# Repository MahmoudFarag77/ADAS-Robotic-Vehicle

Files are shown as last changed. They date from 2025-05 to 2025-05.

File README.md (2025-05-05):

# 🚗 ADAS Robotic Vehicle Prototype – Embedded, Vision, and Control Systems

This project is a fully integrated **Advanced Driver Assistance System (ADAS)** prototype with mechanical steering, embedded control, and computer vision. It simulates real-world ADAS features using a combination of **ESP32**, **Raspberry Pi 4**, **FreeRTOS**, and **YOLOv8**, with an integrated SolidWorks mechanical design.

---

## 🧠 Key ADAS Features

| Feature  | Description |
|---|---|
| **AEB**  | Autonomous Emergency Braking using front ultrasonic sensor |
| **ACC**  | Adaptive Cruise Control with automatic speed regulation |
| **LKA**  | Lane Keeping Assist with dual IR sensors and servo steering |
| **TSDR** | Traffic Sign Detection & Recognition via Raspberry Pi + OpenCV + YOLO |
| **BSW**  | Blind Spot Warning using side-mounted ultrasonic sensors |
| **ALS**  | Adaptive Light System with ambient light sensing and LED control |

---

## ⚙️ System Overview

- **Main Controller:** ESP32 (C++, Arduino IDE)
- **Vision Controller:** Raspberry Pi 4 (Python, OpenCV, YOLO)
- **Communication:** I2C (ESP32 ↔ RPi), UART (ESP32 ↔ Bluetooth)
- **Power:** 2x 18650 Li-ion batteries + 5V 3A RPi power bank

---

## 🛠 Technologies Used

- **Embedded:** ESP32, FreeRTOS
- **Computer Vision:** Raspberry Pi 4, OpenCV, YOLOv8
- **Communication:** I2C, UART (Bluetooth)
- **Mechanical CAD:** SolidWorks 2020
- **Simulation:** Manual testing + real-time behavior demos

---

## 🧰 Bill of Materials (BOM)

View full BOM [here](Docs/BOM.md) or summarized below:

- **Microcontrollers:** ESP32, Raspberry Pi 4
- **Actuators:** 2x DC TT motors, 1x SG90 servo
- **Sensors:** 3x Ultrasonic (HC-SR04), 2x IR, 1x LDR
- **Camera:** Raspberry Pi Camera V1.3
- **Power:** 2x 18650 Li-ion, 1x 5V 3A Power Bank
- **Indicators:** Red, Yellow, and White LEDs for brake, hazard, and headlights

---

## 🧑‍💻 Code Repositories

### 🟦 ESP32 – Embedded Control
📁 [`ESP32_Code/`](ESP32_Code/ESP32_Code.ino)

Implements:
- Manual control via Bluetooth
- AEB, ACC, LKA, BSW, ALS
- Real-time task scheduling with FreeRTOS

### 📚 ESP32 Firmware Dependencies

The following libraries are used in the ESP32 embedded firmware. Make sure they are installed in your Arduino IDE before uploading:

| Library | Use Case |
|---|---|
| `Arduino.h` | Core Arduino functions |
| `freertos/FreeRTOS.h`  | FreeRTOS base for real-time operations |
| `freertos/task.h` | Task creation and management in FreeRTOS |
| `BluetoothSerial.h` | Bluetooth communication with mobile app  |
| `ESP32Servo.h` | Servo control for front wheel steering |
| `Wire.h` | I2C communication with Raspberry Pi |

> 💡 Tip: Most libraries are preinstalled with ESP32 board support in Arduino. If not, install via **Library Manager** (Sketch → Include Library → Manage Libraries).

### 🟨 Raspberry Pi – Computer Vision
📁 [`RaspberryPi_Code/`](RaspberryPi_Code/TSDR.py)

Implements:
- YOLOv8-based TSDR (Traffic Sign Detection and Recognition)
- Python script
- I2C master communication to send detection data to ESP32

### 🧠 Raspberry Pi – TSDR Python Dependencies

The Traffic Sign Detection and Recognition (TSDR) module is written in Python and uses the following libraries:

| Library | Description |
|---|---|
| `cv2` (OpenCV) | Core library for image processing and visualization |
| `picamera2` | Captures real-time video from the Raspberry Pi Camera |
| `ultralytics` | Runs YOLOv8 model for real-time traffic sign detection and classification  |
| `cvzone` | Simplifies display of bounding boxes, FPS counter, etc. |
| `pandas` | (Optional) Used for handling datasets or logging predictions |
| `numpy` | Numerical operations and array handling for image data |
| `smbus2` | I2C communication between Raspberry Pi and ESP32 |
| `time` (built-in) | Delay functions, timeouts, and logging |

> 🛠️ To install manually:
> ```bash
> pip install opencv-python picamera2 ultralytics cvzone pandas numpy smbus2
> ```

---

## 🛠️ Mechanical Design

📁 [`SolidWorks_Model/`](SolidWorks_Model/)

- Full CAD of the 4-wheel chassis
- Steering and motor integration
- Rendered previews available in [`Media/`](Media/)

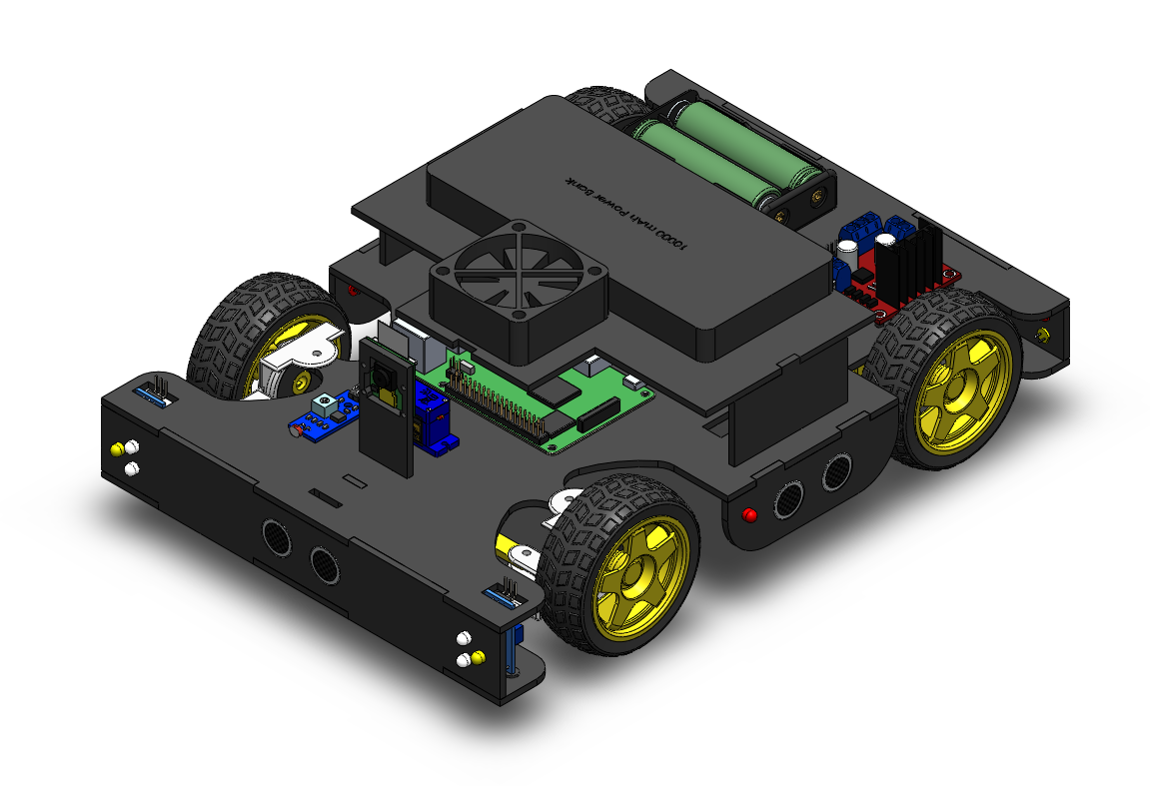
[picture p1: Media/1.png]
Chassis Render


---

## 🎥 Demo

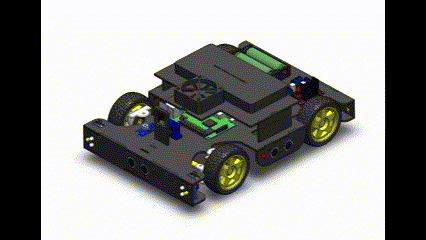
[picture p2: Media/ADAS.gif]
Demo


> 💡 Want to see specific features in action? [Add links to YouTube or external videos if needed]

---

## 🧭 System Architecture
- System Architectures are available in [`Docs/`](Docs/)

---

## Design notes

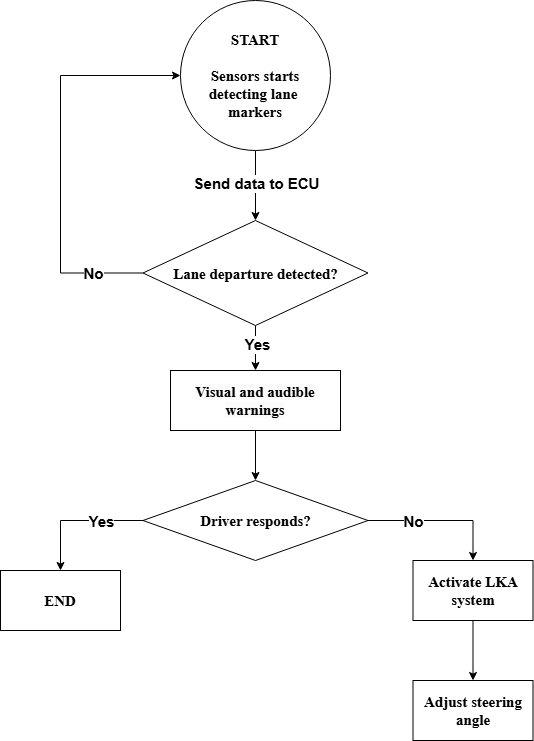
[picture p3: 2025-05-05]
Docs/LKA_FlowChart.png

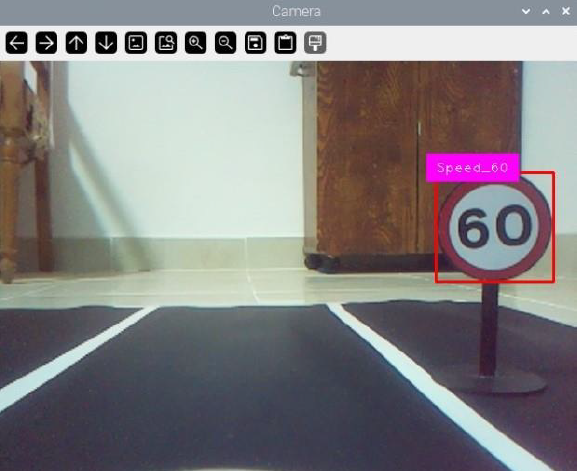
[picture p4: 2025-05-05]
Docs/TSDR_60.png

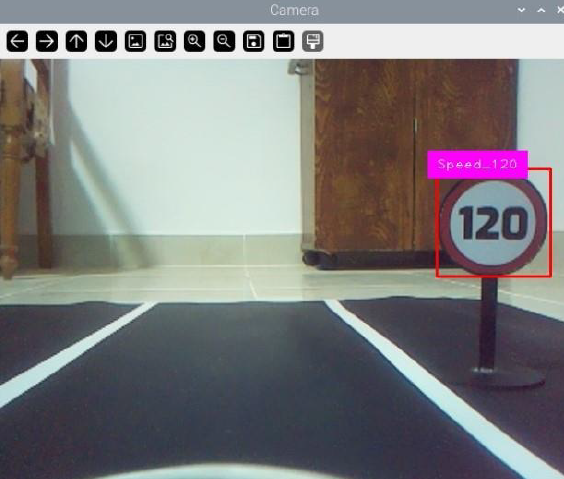
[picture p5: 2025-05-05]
Docs/TSDR_120.png

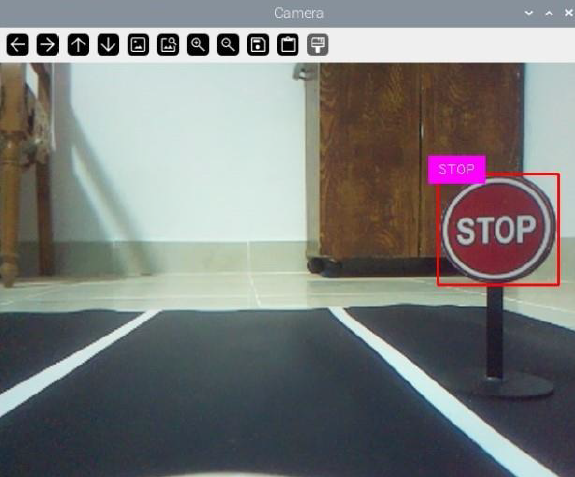
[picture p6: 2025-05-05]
Docs/TSDR_STOP.png

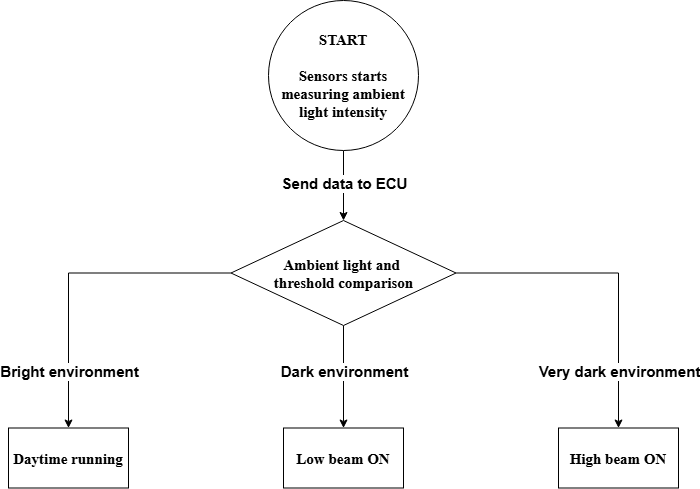
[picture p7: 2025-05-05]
Docs/ALS_FlowChart.png

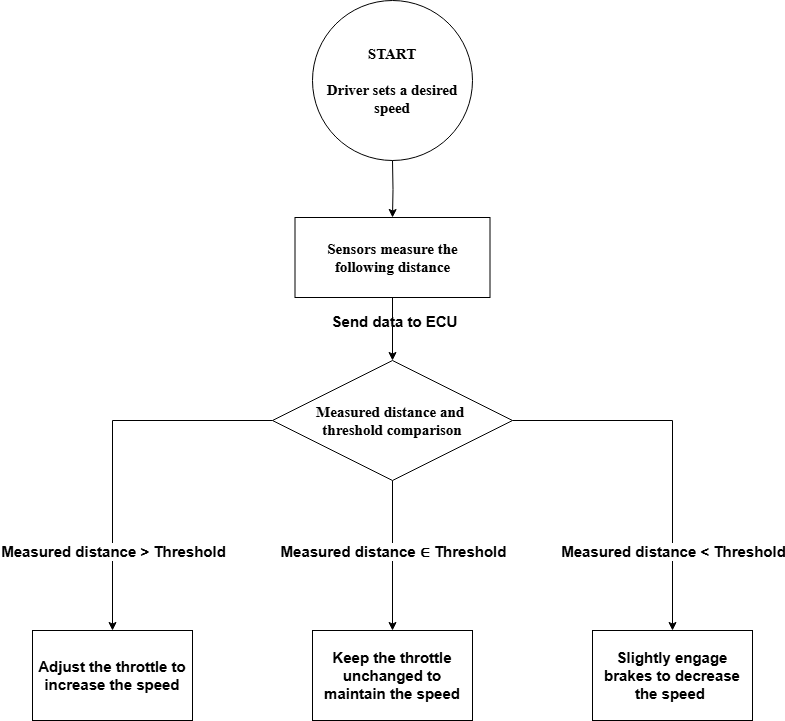
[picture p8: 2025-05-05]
Docs/ACC_FlowChart.png

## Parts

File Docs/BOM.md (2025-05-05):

# 📦 Bill of Materials (BOM) – ADAS Robotic Vehicle Prototype

This document outlines all the electronic components, sensors, actuators, and power elements used in the ADAS robotic vehicle prototype.

---

## 🧠 Microcontrollers & Processing Units

| Item | Quantity | Description |
|---|---|---|
| Raspberry Pi 4 | 1 | Main processor for computer vision (TSDR) |
| ESP32 DevKit | 1 | Main embedded controller for low-level functions |

---

## 🎯 Sensors

| Sensor/Module | Quantity | Functionality |
|---|---|---|
| HC-SR04 Ultrasonic Sensor| 3 | Distance sensing for AEB, ACC, and BSW |
| IR Sensor Module | 2 | Lane detection for LKA |
| LDR Photocell | 1 | Ambient light sensing for ALS |
| Raspberry Pi Camera V1.3 | 1 | Visual input for traffic sign detection (TSDR) |

---

## ⚙️ Actuators & Motors

| Item | Quantity | Description |
|---|---|---|
| DC TT Geared Motor | 2 | Rear wheel drive (left and right motors) |
| SG90 Servo Motor | 1 | Front wheel steering mechanism |
| 5V DC Cooling Fan  | 1 | Raspberry Pi heat management |

---

## 💡 Indicators (LEDs)

| LED Type | Quantity | Functionality |
|---|---|---|
| Red LED | 4 | Brake lights & Blind Spot Warning |
| Yellow LED | 4 | Hazard indicators |
| White LED | 4 | Adaptive headlights (ALS system) |

---

## 🔌 Power & Supply

| Component | Quantity | Description |
|---|---|---|
| 18650 3.7V Battery | 2 | Power supply for motors and ESP32 |
| 5V 3A Power Bank | 1 | Power supply for Raspberry Pi |

---

## 🔧 Electronic Modules

| Module | Quantity | Description |
|---|---|---|
| L298N Motor Driver | 1 | Controls DC motors (rear wheel drive)  |

---

## 🔗 Communication

| Interface | Use Case |
|---|---|
| I2C | Communication between ESP32 and RPi |
| UART (Bluetooth) | Manual control via mobile app |

---

## 🛠️ Software & Development Tools

| Tool/Library | Platform | Purpose |
|---|---|---|
| Arduino IDE | ESP32 | Programming & deployment |
| FreeRTOS | ESP32 | Real-time task scheduling |
| Python + OpenCV | Raspberry Pi  | Image processing (TSDR) |
| YOLOv8 | Raspberry Pi  | Traffic sign detection & recognition|

---

> 📝 *All items were selected based on low cost, availability, and ease of integration for prototyping purposes.*

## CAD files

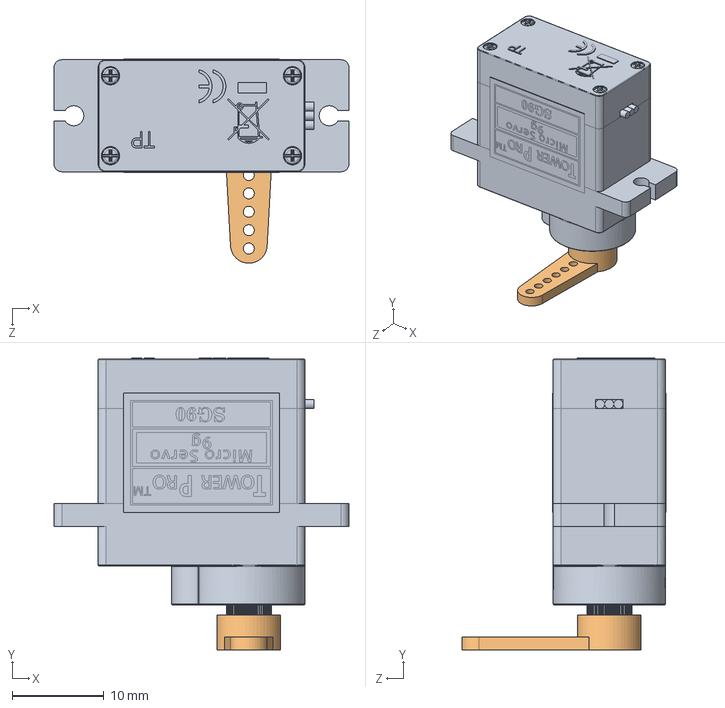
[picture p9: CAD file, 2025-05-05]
SolidWorks_Model/Servo Assembly.SLDASM
32.1 x 31.8 x 22.2 mm
SG90 Servo
SG90 Arm

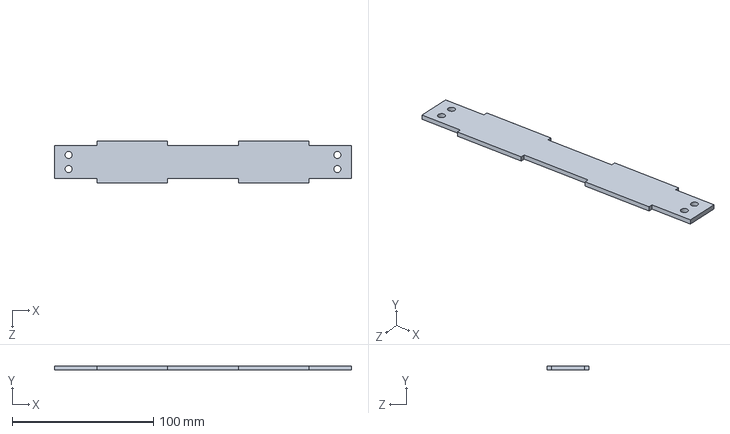
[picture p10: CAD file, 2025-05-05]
SolidWorks_Model/Back.SLDPRT
210.0 x 3.00 x 29.7 mm

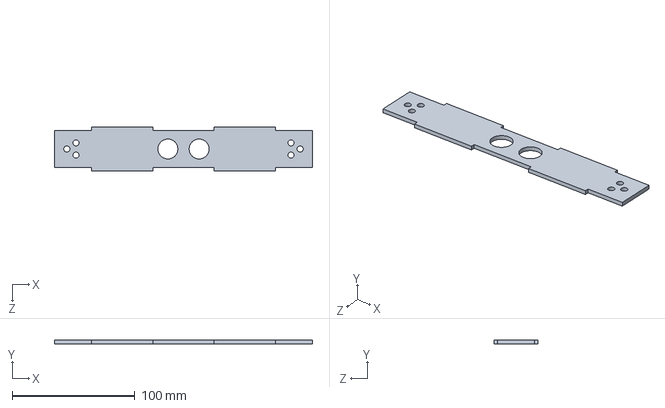
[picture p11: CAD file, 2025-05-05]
SolidWorks_Model/Front.SLDPRT
210.0 x 3.00 x 36.0 mm

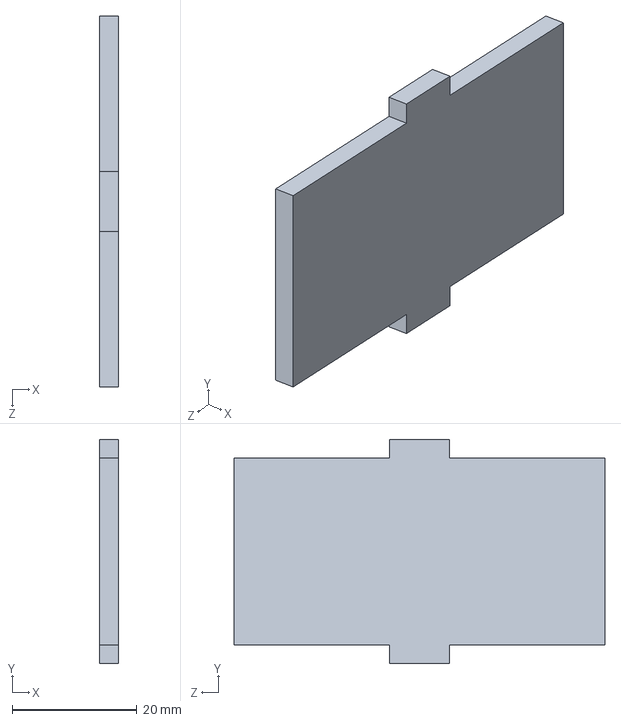
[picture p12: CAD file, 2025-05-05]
SolidWorks_Model/PowerBank Holder1.SLDPRT
3.00 x 36.0 x 59.6 mm

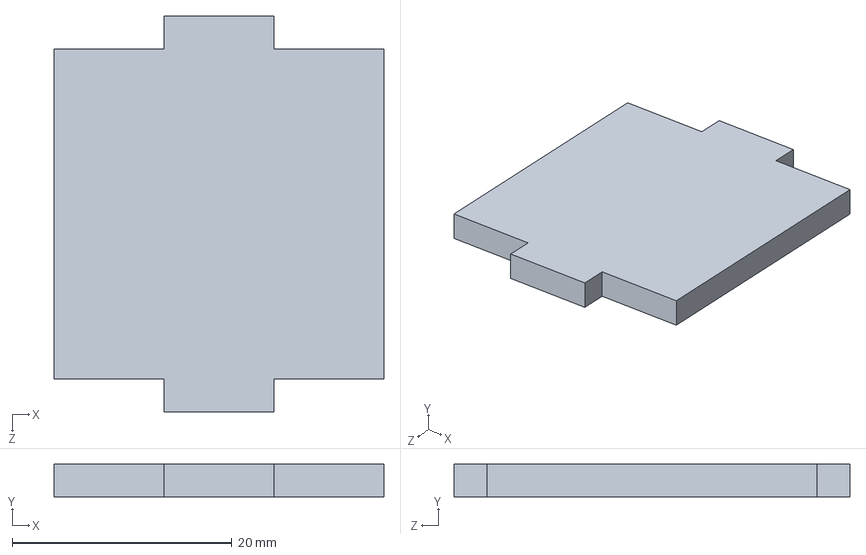
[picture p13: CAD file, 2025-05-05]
SolidWorks_Model/Chasis Support.SLDPRT
30.0 x 3.00 x 36.0 mm

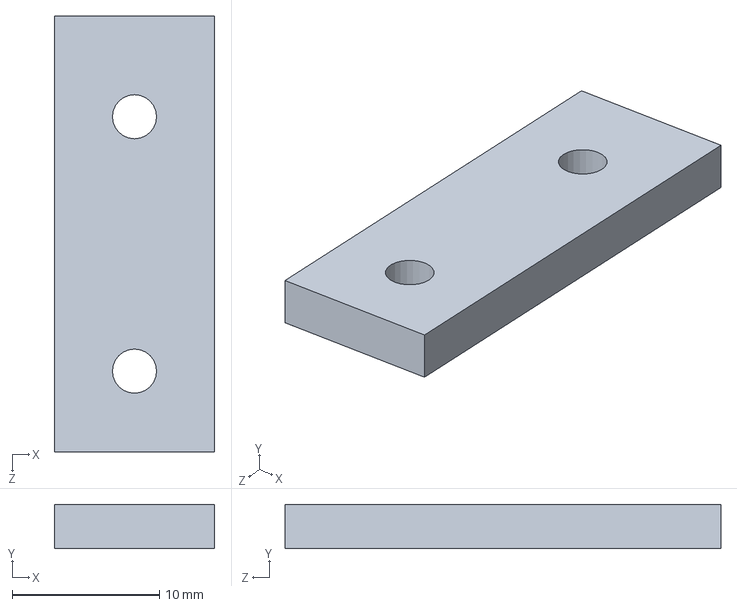
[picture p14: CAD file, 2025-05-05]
SolidWorks_Model/Motor Holder.SLDPRT
10.9 x 3.00 x 29.6 mm

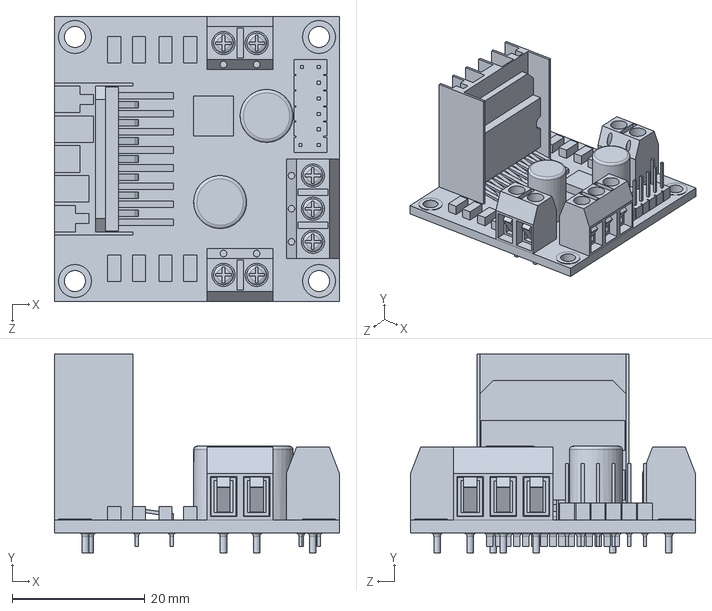
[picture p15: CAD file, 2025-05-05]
SolidWorks_Model/L298N Motor Driver.SLDPRT
43.0 x 30.0 x 43.0 mm

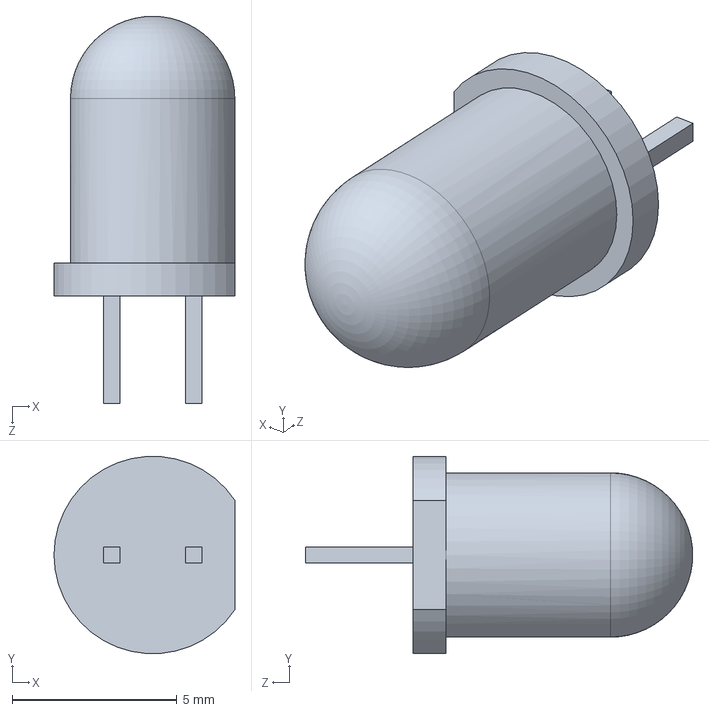
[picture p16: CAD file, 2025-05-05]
SolidWorks_Model/White LED.SLDPRT
5.50 x 5.99 x 11.8 mm

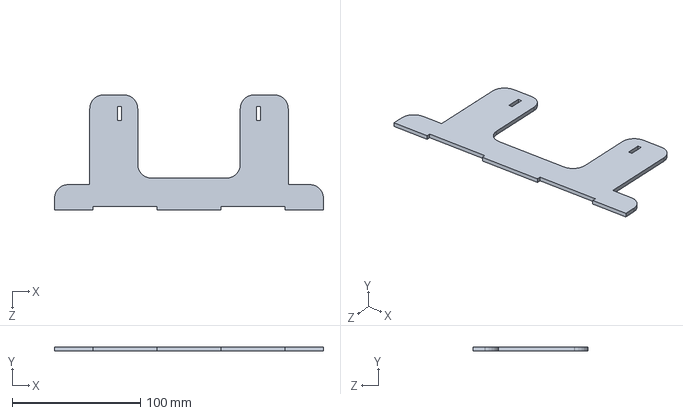
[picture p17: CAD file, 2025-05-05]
SolidWorks_Model/Under Chasis 2.SLDPRT
210.0 x 3.00 x 90.0 mm

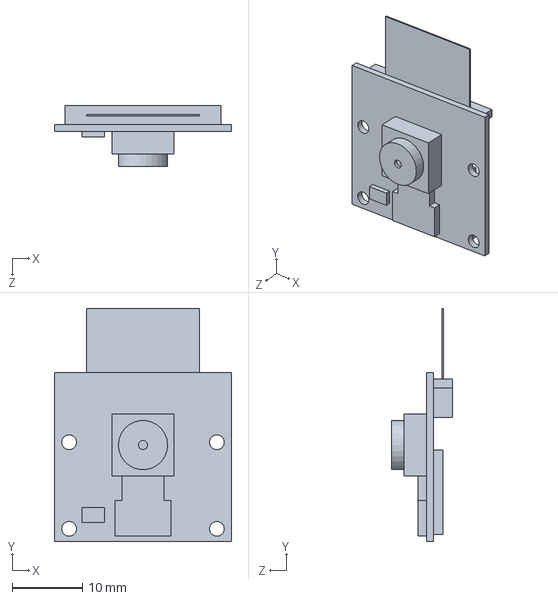
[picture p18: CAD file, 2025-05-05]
SolidWorks_Model/RPi Camera Rev 1.3.SLDPRT
25.2 x 33.1 x 8.70 mm

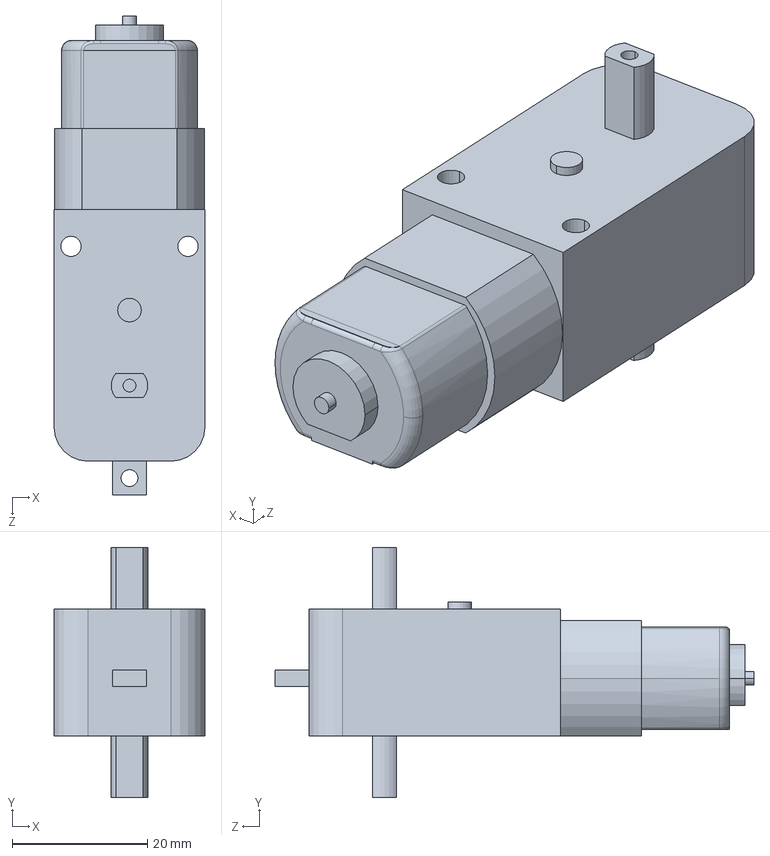
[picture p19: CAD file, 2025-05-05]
SolidWorks_Model/Motor.SLDPRT
22.3 x 37.0 x 70.8 mm

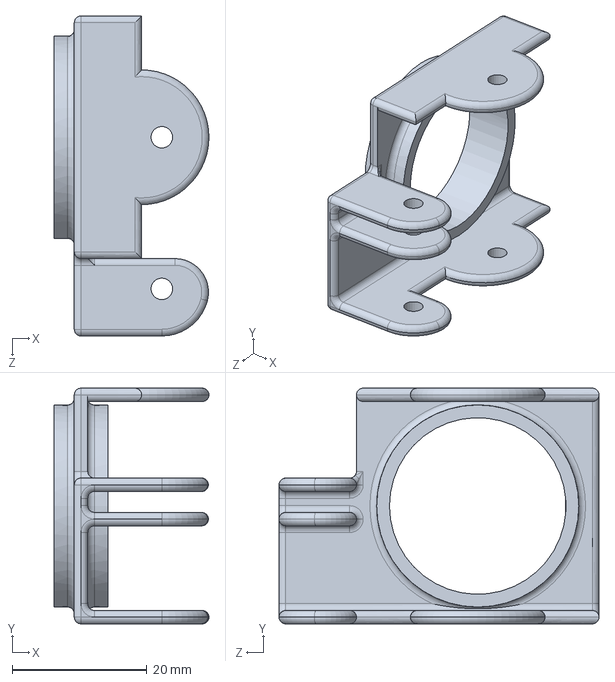
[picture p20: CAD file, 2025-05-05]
SolidWorks_Model/Right Arm.SLDPRT
23.0 x 35.0 x 47.5 mm

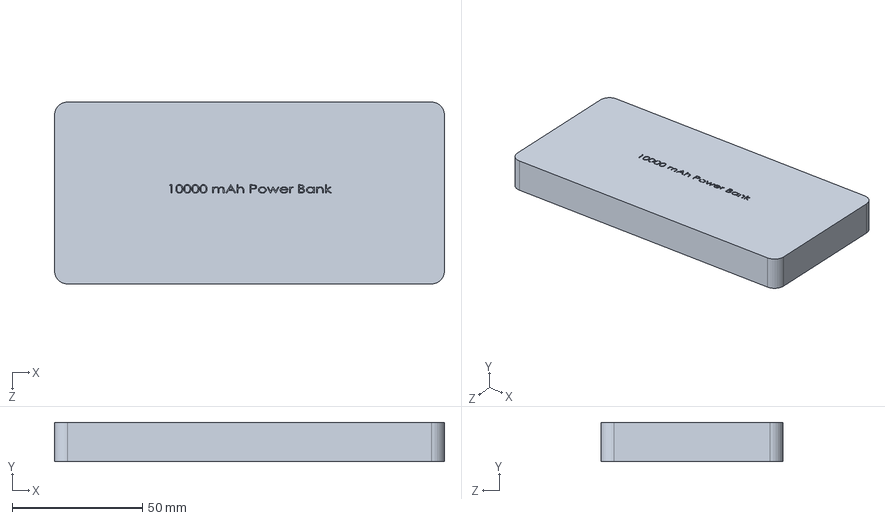
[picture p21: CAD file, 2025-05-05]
SolidWorks_Model/PowerBank.SLDPRT
150.0 x 15.0 x 70.0 mm

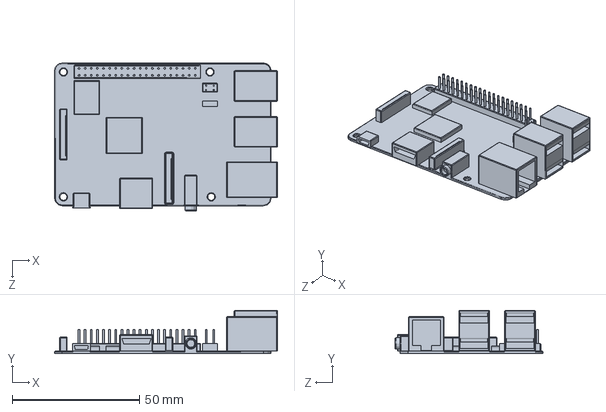
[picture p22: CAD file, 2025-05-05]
SolidWorks_Model/RaspberryPi3.SLDPRT
87.5 x 17.0 x 58.0 mm

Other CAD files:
SolidWorks_Model/SG90 Servo.SLDPRT
SolidWorks_Model/Steering Servo Arm.SLDPRT
SolidWorks_Model/SG90 Arm.SLDPRT
SolidWorks_Model/Yellow LED.SLDPRT
SolidWorks_Model/6000 Ball Bearing.SLDPRT
SolidWorks_Model/BATTERY HOLDER 2X18650.stp
SolidWorks_Model/Camera Holder.SLDPRT
SolidWorks_Model/Chasis.SLDPRT
SolidWorks_Model/Fan.SLDPRT
SolidWorks_Model/HCSR04 Ultrasonic Sensor.SLDPRT
SolidWorks_Model/IR Sensor.SLDPRT
SolidWorks_Model/LDR.step
SolidWorks_Model/Left Arm.SLDPRT
SolidWorks_Model/PowerBank Holder2.SLDPRT
SolidWorks_Model/Red LED.SLDPRT
SolidWorks_Model/Side.SLDPRT
SolidWorks_Model/Under Chasis.SLDPRT
SolidWorks_Model/Wheel.SLDPRT

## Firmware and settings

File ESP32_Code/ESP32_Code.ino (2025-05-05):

#include <Arduino.h>              // Standard Arduino Library
#include <freertos/FreeRTOS.h>    // FreeRTOS Main Library
#include <freertos/task.h>        // FreeRTOS Tasks Library
#include "BluetoothSerial.h"      // Bluetooth library
#include <ESP32Servo.h>           // Servo Motor library
#include <Wire.h>                 // I2C Protocol library

// Bluetooth Serial
BluetoothSerial serialBT;
// Queue to hold received I2C signals
QueueHandle_t signalQueue;

// --- Pins Delcaration ---
// L298N H-Bridge (DC Motor Driver)
#define EN_A 32
#define IN_1 33
#define IN_2 25
#define IN_3 26
#define IN_4 27
#define EN_B 14
// SG90 Servo (Steering Servo)
Servo SteeringServo;
#define SteeringPin 18
// Front Ultrasonic Sensor (AEB and ACC)
#define FRONT_ULTRASONIC_TRIGGER_PIN 3
#define FRONT_ULTRASONIC_ECHO_PIN 34
// Blinkers LEDs (Blinkers and Brake LEDs)
#define BACK_STOP_LED 23
#define LEFT_LED_BLINKER 19
#define RIGHT_LED_BLINKER 5
// IR Sensors (LKA)
#define LEFT_IR 35
#define RIGHT_IR 39
// Left Ultrasonic Sensor and LED (BSW)
#define ULTRASONIC_TRIGGER_LEFT_PIN 15
#define ULTRASONIC_ECHO_LEFT_PIN 2
#define LEFT_BSW_LED 16
// Right Ultrasonic Sensor and LED (BSW)
#define ULTRASONIC_TRIGGER_RIGHT_PIN 0
#define ULTRASONIC_ECHO_RIGHT_PIN 4
#define RIGHT_BSW_LED 17
// LDR and Front LEDs (ALS)
#define ANALOG_LDR_PIN 36
#define HIGH_BEAM_LED 13
#define LOW_BEAM_LED 12
// Define I2C address
#define I2C_ADDRESS 0x08

// --- Macro Values --- 
// AEB Macros
#define AEB_Threshold 25
// ACC Macros
#define ACC_Decrease_Threshold 50
#define ACC_Increase_Threshold 80
// TSDR Macros 
#define SPEED_LIMIT_60 180        // Speed Limit = 180 PWM
#define SPEED_LIMIT_120 220       // Speed Limit = 220 PWM
#define STOP_Time 5000            // Time to STOP before moving again (STOP Sign)
#define NO_SPEED_LIMIT 255        // No Speed Limit
// LKA Macros
#define STRAIGHT 90               // Servo angle 90
#define LEFT 60                   // Servo angle 60
#define LKA_LEFT 75               // Servo angle 75
#define RIGHT 120                 // Servo angle 120
#define LKA_RIGHT 105             // Servo angle 105
// BSW Macros
#define BSW_Distance 20
// ALS Macros
#define DAY_RUNNING_LED 20
#define ALS_Threshold_1 750
#define ALS_Threshold_2 2500
#define ALS_Threshold_3 3500

// --- Global Variables ---
// Bluetooth Connection Variables
char btSignal;                    // char to recieve bluetooth signal
char Recall_Signal;               // char for recalling recieved bluetooth signal
char Last_BT_STOP;                // char for recalling last recieved bluetooth signal after detecting STOP sign (TSDR)
// Speed Variables
int SPEED = 130;                  // Speed value (PWM) (Initially = 130 PWM)
int OLD_SPEED;                    // To stop printing same speed value
int MAX_SPEED = 255;              // Maximum speed value (PWM) (TSDR)   -- Initially No Speed Limit
// Blinkers Variables
int BLINKER_VALUE = 1;            // Blinker LEDs initial value
int LEFT_BLINKER_STATE = 0;       // Left sign LED Activate/Deactivate  -- Initially OFF
int RIGHT_BLINKER_STATE = 0;      // Right sign LED Activate/Deactivate -- Initially OFF
// AEB Variables
int AEB_Counter = 0;              // AEB distance counter
// LKA Variables
int LKA_Counter = 0;              // LKA Error counter
// BSW Variables
int LBSW_LED_VALUE = 1;           // LBSW LED initial value
int RBSW_LED_VALUE = 1;           // RBSW LED initial value
// ADAS Features Variables 
int ACC_STATE = 0;                // ACC Function Activate/Deactivate   -- Initially OFF
int TSDR_STATE = 0;               // TSDR Function Activate/Deactivate  -- Initially OFF
int LKA_STATE = 0;                // LKA Function Activate/Deactivate   -- Initially OFF
int ALS_STATE = 0;                // ALS Function Activate/Deactivate   -- Initially OFF

// Moving forward function (Anti-clockwise)
void Forward(){
  digitalWrite(IN_1,LOW);
  digitalWrite(IN_2,HIGH);
  digitalWrite(IN_3,HIGH);
  digitalWrite(IN_4,LOW);
  analogWrite(EN_A,SPEED);
  analogWrite(EN_B,SPEED);
  // Turn off brake LED
  digitalWrite(BACK_STOP_LED, LOW);
}

// Moving backward function (Clockwisse)
void Backward(){
  digitalWrite(IN_1,HIGH);
  digitalWrite(IN_2,LOW);
  digitalWrite(IN_3,LOW);
  digitalWrite(IN_4,HIGH);
  analogWrite(EN_A,SPEED);
  analogWrite(EN_B,SPEED);
  // Turn off brake LED
  digitalWrite(BACK_STOP_LED, LOW);
}

// Stop function 
void Stop(){
  digitalWrite(IN_1,LOW);
  digitalWrite(IN_2,LOW);
  digitalWrite(IN_3,LOW);
  digitalWrite(IN_4,LOW);
  analogWrite(EN_A,SPEED);
  analogWrite(EN_B,SPEED);
  // Reset the initial speed value
  SPEED = 130;
  // Turn ON brake LED
  digitalWrite(BACK_STOP_LED, HIGH);
}

// Bluetooth recieve FreeRTOS Function
void BT_Receive(void *pvParameters){
  while(1){
    while(serialBT.available()){
      btSignal = serialBT.read();
      // Move Forward
      if(btSignal == 'f'){
        Recall_Signal = 'f';
        LEFT_BLINKER_STATE = 0;
        RIGHT_BLINKER_STATE = 0;
        serialBT.print("Speed = ");
        serialBT.println(SPEED);
        AEB_Counter = 0;
        // Force STOP ACC
        if(ACC_STATE == 1){
          ACC_STATE = 0;
          serialBT.println("ACC OFF");
        }
      }
      // Move Backward
      if(btSignal == 'b'){
        Recall_Signal = 'b';
        LEFT_BLINKER_STATE = 0;
        RIGHT_BLINKER_STATE = 0;
        serialBT.print("Speed = ");
        serialBT.println(SPEED);
        AEB_Counter = 0;
        // Force STOP ACC
        if(ACC_STATE == 1){
          ACC_STATE = 0;
          serialBT.println("ACC OFF");
        }
      }
      // Steer Left
      if(btSignal == 'l'){
        SteeringServo.write(LEFT);
        LEFT_BLINKER_STATE = 1;
        RIGHT_BLINKER_STATE = 0;
        // Force STOP LKA
        if(LKA_STATE == 1){
          LKA_STATE = 0;
          serialBT.println("LKA OFF");
        }
      }
      // Steer Right
      if(btSignal == 'r'){
        SteeringServo.write(RIGHT);
        LEFT_BLINKER_STATE = 0;
        RIGHT_BLINKER_STATE = 1;
        // Force STOP LKA
        if(LKA_STATE == 1){
          LKA_STATE = 0;
          serialBT.println("LKA OFF");
        }
      }
      // Steer Straight
      if(btSignal == 'n'){
        SteeringServo.write(STRAIGHT);
        LEFT_BLINKER_STATE = 0;
        RIGHT_BLINKER_STATE = 0;
        // Force STOP LKA
        if(LKA_STATE == 1){
          LKA_STATE = 0;
          serialBT.println("LKA OFF");
        }
      }
      // STOP
      if(btSignal == 's'){
        Recall_Signal = 's';
        SteeringServo.write(STRAIGHT);
        LEFT_BLINKER_STATE = 0;
        RIGHT_BLINKER_STATE = 0;
        // Force STOP ACC
        if(ACC_STATE == 1){
          ACC_STATE = 0;
          serialBT.println("ACC OFF");
        }
        // Force STOP LKA
        if(LKA_STATE == 1){
          LKA_STATE = 0;
          serialBT.println("LKA OFF");
        }
      }
      // Turn ON Hazard LEDs
      if(btSignal == 'h'){  
        LEFT_BLINKER_STATE = 1;
        RIGHT_BLINKER_STATE = 1;
      }
      // Turn OFF Hazard LEDs
      if(btSignal == 'k'){  
        LEFT_BLINKER_STATE = 0;
        RIGHT_BLINKER_STATE = 0;
      }
      // Increase Speed Manually
      if(btSignal == 'i'){
        if(SPEED < MAX_SPEED){
          OLD_SPEED = SPEED;
          SPEED = OLD_SPEED + 5;
          if(OLD_SPEED != SPEED){
            serialBT.print("Speed = ");
            serialBT.println(SPEED);
          }
        }
        // Force STOP ACC
        if(ACC_STATE == 1){
          ACC_STATE = 0;
          serialBT.println("ACC OFF");
        }
      }
      // Decrease Speed Manually
      if(btSignal == 'd'){
        if(SPEED > 130){
          OLD_SPEED = SPEED;
          SPEED = OLD_SPEED - 5;
          if(OLD_SPEED != SPEED){
            serialBT.print("Speed = ");
            serialBT.println(SPEED);
          }
        }
        // Force STOP ACC
        if(ACC_STATE == 1){
          ACC_STATE = 0;
          serialBT.println("ACC OFF");
        }
      }
      // Activate ACC
      if(btSignal == 'x'){
        if(ACC_STATE == 0){
          ACC_STATE = 1;
          serialBT.println("ACC ON");
        }
      }
      // Deactivate ACC
      if(btSignal == 'y'){
        if(ACC_STATE == 1){
          ACC_STATE = 0;
          serialBT.println("ACC OFF");
        }
      }
      // Activate TSDR
      if(btSignal == 'z'){
        if(TSDR_STATE == 0){
          TSDR_STATE = 1;
          serialBT.println("TSDR ON");
        }
      }
      // Deactivate TSDR
      if(btSignal == 'q'){
        if(TSDR_STATE == 1){
          TSDR_STATE = 0;
          serialBT.println("TSDR OFF");
        }
      }  
      // Activate LKA
      if(btSignal == 'a'){
        if(LKA_STATE == 0){
          LKA_STATE = 1;
          serialBT.println("LKA ON");
        }
      } 
      // Deactivate LKA
      if(btSignal == 'e'){
        if(LKA_STATE == 1){
          LKA_STATE = 0;
          serialBT.println("LKA OFF");
        }
      } 
      // Activate ALS
      if(btSignal == 'g'){
        if(ALS_STATE == 0){
          ALS_STATE = 1;
          serialBT.println("ALS ON");
        }
      } 
      // Deactivate ALS
      if(btSignal == 'w'){
        if(ALS_STATE == 1){
          ALS_STATE = 0;
          serialBT.println("ALS OFF");
          // Turn OFF Front LEDs
          analogWrite(LOW_BEAM_LED, 0);
          digitalWrite(HIGH_BEAM_LED, LOW);
        }
      } 
      // Turn OFF Front LEDs
      if(btSignal == 'c'){
        if(ALS_STATE == 1){
          ALS_STATE = 0;
          serialBT.println("ALS OFF");
        }
        analogWrite(LOW_BEAM_LED, 0);
        digitalWrite(HIGH_BEAM_LED, LOW);
      }
      // Turn ON Day Running Lights
      if(btSignal == 't'){
        if(ALS_STATE == 1){
          ALS_STATE = 0;
          serialBT.println("ALS OFF");
        }
        analogWrite(LOW_BEAM_LED, DAY_RUNNING_LED);
        digitalWrite(HIGH_BEAM_LED, LOW);
      }
      // Turn ON Low Beam LED
      if(btSignal == 'j'){
        if(ALS_STATE == 1){
          ALS_STATE = 0;
          serialBT.println("ALS OFF");
        }
        analogWrite(LOW_BEAM_LED, 255);
        digitalWrite(HIGH_BEAM_LED, LOW);
      }
      // Turn ON HIGH Beam LED
      if(btSignal == 'p'){
        if(ALS_STATE == 1){
          ALS_STATE = 0;
          serialBT.println("ALS OFF");
        }
        analogWrite(LOW_BEAM_LED, 255);
        digitalWrite(HIGH_BEAM_LED, HIGH);
      }
    }
    vTaskDelay(pdMS_TO_TICKS(500));
  }
}

// Bluetooth Recall FreeRTOS Function
void BT_Control(void *pvParameters){
  while(1){
    if(Recall_Signal == 'f')  Forward();
    if(Recall_Signal == 'b')  Backward();
    if(Recall_Signal == 's')  Stop();
    vTaskDelay(pdMS_TO_TICKS(500));
  }
}

// Blinkers FreeRTOS Function
void Blinker_LEDs(void *pvParameters){
  while(1){
    if(LEFT_BLINKER_STATE == 0){ 
      digitalWrite(LEFT_LED_BLINKER, LOW);
    }
    if(RIGHT_BLINKER_STATE == 0){ 
      digitalWrite(RIGHT_LED_BLINKER, LOW);
    }
    if(LEFT_BLINKER_STATE == 1 && RIGHT_BLINKER_STATE == 0){
      digitalWrite(LEFT_LED_BLINKER, BLINKER_VALUE);
      BLINKER_VALUE =! BLINKER_VALUE;
    }
    if(LEFT_BLINKER_STATE == 0 && RIGHT_BLINKER_STATE == 1){
      digitalWrite(RIGHT_LED_BLINKER, BLINKER_VALUE);
      BLINKER_VALUE =! BLINKER_VALUE;
    }
    if(LEFT_BLINKER_STATE == 1 && RIGHT_BLINKER_STATE == 1){
      digitalWrite(LEFT_LED_BLINKER, BLINKER_VALUE);
      digitalWrite(RIGHT_LED_BLINKER, BLINKER_VALUE);
      BLINKER_VALUE =! BLINKER_VALUE;
    }
    vTaskDelay(pdMS_TO_TICKS(500));
  }
}

// AEB and ACC FreeRTOS Function
void AEB_ACC(void *pvParameters){
  while(1){
    digitalWrite(FRONT_ULTRASONIC_TRIGGER_PIN, LOW);
    delayMicroseconds(2);
    digitalWrite(FRONT_ULTRASONIC_TRIGGER_PIN, HIGH);
    delayMicroseconds(10);
    digitalWrite(FRONT_ULTRASONIC_TRIGGER_PIN, LOW);
    unsigned long pulseDuration = pulseIn(FRONT_ULTRASONIC_ECHO_PIN, HIGH);
    float Front_Distance_CM = pulseDuration * 0.0343 / 2;

    // Autonomous Emergency Braking (AEB)
    if(Front_Distance_CM > 2 && Front_Distance_CM <= AEB_Threshold && Recall_Signal == 'f'){
      if(AEB_Counter == 0){
        Stop();
        Recall_Signal = 's';
        LEFT_BLINKER_STATE = 1;
        RIGHT_BLINKER_STATE = 1;
        AEB_Counter = 1;
        serialBT.println("STOP (AEB)");
        // Force STOP ACC
        if(ACC_STATE == 1){
          ACC_STATE = 0;
          serialBT.println("ACC OFF");
        }
        // Force STOP LKA
        if(LKA_STATE == 1){
          LKA_STATE = 0;
          serialBT.println("LKA OFF");
        }
      }
    }

    // Adaptive Cruise Control (ACC)
    if(ACC_STATE == 1){
      // Decrease Speed
      if(Front_Distance_CM > AEB_Threshold && Front_Distance_CM <= ACC_Decrease_Threshold){
        if(SPEED > 130){
          OLD_SPEED = SPEED;
          SPEED = OLD_SPEED - 5;
          if(OLD_SPEED != SPEED){
            serialBT.print("Speed = ");
            serialBT.println(SPEED);
          }
        }
      }
      // Increase Speed
      if(Front_Distance_CM > ACC_Increase_Threshold){
        if(SPEED < MAX_SPEED){
          OLD_SPEED = SPEED;
          SPEED = OLD_SPEED + 5;
          if(OLD_SPEED != SPEED){
            serialBT.print("Speed = ");
            serialBT.println(SPEED);
          }
        }
      }
    }
    vTaskDelay(pdMS_TO_TICKS(300));
  }
}

// TSDR Functions from RaspberryPi I2C communication protocol
// I2C receive event
void receiveEvent(int howMany) {
  while (Wire.available()) {
    int signal = Wire.read();
    xQueueSend(signalQueue, &signal, portMAX_DELAY);
  }
}
// FreeRTOS task to handle I2C signals
void i2cTask(void *pvParameters) {
  int receivedSignal;
  while (1) {
    if (xQueueReceive(signalQueue, &receivedSignal, portMAX_DELAY) == pdPASS) {
      handleSignal(receivedSignal);
    }
  }
}
// TSDR Function
void handleSignal(int signal) {
  if(TSDR_STATE == 1){
    switch(signal){
      // Speed Limit 60 km/h Sign
      case 1:
        MAX_SPEED = SPEED_LIMIT_60;
        serialBT.println("Speed Limit 60 km/h");
        serialBT.println("Speed Limit 180 PWM");
        if(SPEED > 180){
          SPEED = 180;
        }
        break;
      // Speed Limit 120 km/h Sign
      case 2:
        MAX_SPEED = SPEED_LIMIT_120;
        serialBT.println("Speed Limit 120 km/h");
        serialBT.println("Speed Limit 220 PWM");
        if(SPEED > 220){
          SPEED = 220;
        }
        break;
      // STOP Sign
      case 3:
        Last_BT_STOP = Recall_Signal;
        Stop();
        Recall_Signal = 's';
        serialBT.println("STOP Sign");
        delay(STOP_Time);
        MAX_SPEED = NO_SPEED_LIMIT;
        serialBT.println("No Speed Limit");
        serialBT.println("Speed Limit 255 PWM");
        Recall_Signal = Last_BT_STOP;
        serialBT.println("TSDR OFF");
        TSDR_STATE = 0;
        break;
    }
  }
}

// LKA FreeRTOS Function
void LKA(void *pvParameters){
  while(1){
    if(LKA_STATE == 1){
      int RIGHT_IR_READING = digitalRead(RIGHT_IR);
      int LEFT_IR_READING = digitalRead(LEFT_IR);
      // IN LANE
      if(RIGHT_IR_READING == HIGH && LEFT_IR_READING == HIGH){
        SteeringServo.write(STRAIGHT);
        LKA_Counter = 0;
      }
      // Turn Left
      else if(RIGHT_IR_READING == LOW && LEFT_IR_READING == HIGH){
        SteeringServo.write(LKA_LEFT);
        LKA_Counter = 0;
      }
      // Turn Right
      else if(RIGHT_IR_READING == HIGH && LEFT_IR_READING == LOW){
        SteeringServo.write(LKA_RIGHT);
        LKA_Counter = 0;
      }
      // ERROR Readings
      if(RIGHT_IR_READING == LOW && LEFT_IR_READING == LOW){
        SteeringServo.write(STRAIGHT);
        LKA_Counter ++;
        serialBT.println("LKA ERROR");
        if(LKA_Counter >= 3){
          LKA_STATE = 0;
          LKA_Counter = 0;
          serialBT.println("LKA OFF");
        }
      }
    }
    vTaskDelay(pdMS_TO_TICKS(500));
  }
}

// Right BSW FreeRTOS Function
void Right_BSW(void *pvParameters){
  while(1){
    digitalWrite(ULTRASONIC_TRIGGER_RIGHT_PIN, LOW);
    delayMicroseconds(2);
    digitalWrite(ULTRASONIC_TRIGGER_RIGHT_PIN, HIGH);
    delayMicroseconds(10);
    digitalWrite(ULTRASONIC_TRIGGER_RIGHT_PIN, LOW);
    unsigned long pulseDuration = pulseIn(ULTRASONIC_ECHO_RIGHT_PIN, HIGH);
    float Right_Distance = pulseDuration * 0.0343 / 2;
    if(Right_Distance <= BSW_Distance){
      digitalWrite(RIGHT_BSW_LED, RBSW_LED_VALUE);
      RBSW_LED_VALUE =! RBSW_LED_VALUE;
    }
    else{
      digitalWrite(RIGHT_BSW_LED, LOW);
      RBSW_LED_VALUE = 1;
    }
    vTaskDelay(pdMS_TO_TICKS(300));
  }
}

// Left BSW FreeRTOS Function
void Left_BSW(void *pvParameters){
  while(1){
    digitalWrite(ULTRASONIC_TRIGGER_LEFT_PIN, LOW);
    delayMicroseconds(2);
    digitalWrite(ULTRASONIC_TRIGGER_LEFT_PIN, HIGH);
    delayMicroseconds(10);
    digitalWrite(ULTRASONIC_TRIGGER_LEFT_PIN, LOW);
    unsigned long pulseDuration = pulseIn(ULTRASONIC_ECHO_LEFT_PIN, HIGH);
    float Left_Distance = pulseDuration * 0.0343 / 2;
    if(Left_Distance <= BSW_Distance){
      digitalWrite(LEFT_BSW_LED, LBSW_LED_VALUE);
      LBSW_LED_VALUE =! LBSW_LED_VALUE;
    }
    else{
      digitalWrite(LEFT_BSW_LED, LOW);
      LBSW_LED_VALUE = 1;
    }
    vTaskDelay(pdMS_TO_TICKS(300));
  }
}

// ALS FreeRTOS Function
void ALS(void *pvParameters){
  while(1){
    if(ALS_STATE == 1){
      int LDR_Value = analogRead(ANALOG_LDR_PIN);
      // Very bright ambient environment -> Turn OFF all LEDs
      if(LDR_Value < ALS_Threshold_1){
        analogWrite(LOW_BEAM_LED, 0);
        digitalWrite(HIGH_BEAM_LED, LOW);
      }
      // Bright ambient environment -> Turn ON Day Running Lights
      if(LDR_Value > ALS_Threshold_1 && LDR_Value < ALS_Threshold_2){
        analogWrite(LOW_BEAM_LED, DAY_RUNNING_LED);
        digitalWrite(HIGH_BEAM_LED, LOW);
      }
      // Dark ambient environment -> Turn ON Low Beam LED
      if(LDR_Value > ALS_Threshold_2 && LDR_Value < ALS_Threshold_3){
        analogWrite(LOW_BEAM_LED, 255);
        digitalWrite(HIGH_BEAM_LED, LOW);
      }
      // Very dark ambient environment -> Turn ON High Beam LED
      if(LDR_Value > ALS_Threshold_3){
        analogWrite(LOW_BEAM_LED, 255);
        digitalWrite(HIGH_BEAM_LED, HIGH);
      }
    }
    vTaskDelay(pdMS_TO_TICKS(500));  
  }
}

void setup(){
  Serial.begin(115200);
  // Bluetooth device Setup
  serialBT.begin("FARAG - ADAS");
  // Create I2C queue
  signalQueue = xQueueCreate(10, sizeof(int));
  if (signalQueue == NULL) {
    Serial.println("Failed to create queue");
    while (1); // Stop if queue creation failed
  }
  Wire.begin(I2C_ADDRESS);
  Wire.onReceive(receiveEvent); 
  // L298N Pins Setup
  pinMode(EN_A, OUTPUT);
  pinMode(IN_1, OUTPUT);
  pinMode(IN_2, OUTPUT);
  pinMode(IN_3, OUTPUT);
  pinMode(IN_4, OUTPUT);
  pinMode(EN_B, OUTPUT);
  // SG90 Servo Pins Setup
  SteeringServo.attach(SteeringPin);
  SteeringServo.write(STRAIGHT);
  // Front Ultrasonic Sensor Pins Setup
  pinMode(FRONT_ULTRASONIC_TRIGGER_PIN, OUTPUT);
  pinMode(FRONT_ULTRASONIC_ECHO_PIN, INPUT);
  // Blinkers LEDs Pins Setup
  pinMode(BACK_STOP_LED, OUTPUT);
  pinMode(LEFT_LED_BLINKER, OUTPUT);
  pinMode(RIGHT_LED_BLINKER, OUTPUT);
  // IR Sensors Pins Setup
  pinMode(LEFT_IR, INPUT);
  pinMode(RIGHT_IR, INPUT);
  // Left Ultrasonic Sensor and LED Pins Setup
  pinMode(ULTRASONIC_TRIGGER_LEFT_PIN, OUTPUT);
  pinMode(ULTRASONIC_ECHO_LEFT_PIN, INPUT);
  pinMode(LEFT_BSW_LED, OUTPUT);
  // Right Ultrasonic Sensor and LED Pins Setup
  pinMode(ULTRASONIC_TRIGGER_RIGHT_PIN, OUTPUT);
  pinMode(ULTRASONIC_ECHO_RIGHT_PIN, INPUT);
  pinMode(RIGHT_BSW_LED, OUTPUT);
  // LDR and Front LEDs Pins Setup
  pinMode(ANALOG_LDR_PIN, INPUT);
  pinMode(HIGH_BEAM_LED, OUTPUT);
  pinMode(LOW_BEAM_LED, OUTPUT);
  // FreeRTOS Task Creation
  xTaskCreate(BT_Receive,"BT_Receive",3000,NULL,2,NULL);
  xTaskCreate(BT_Control,"BT_Control",3000,NULL,2,NULL);
  xTaskCreate(Blinker_LEDs,"Blinker_LEDs",3000,NULL,1,NULL);
  xTaskCreate(AEB_ACC,"AEB_ACC",4000,NULL,4,NULL);
  xTaskCreate(i2cTask,"I2C Task",3000,NULL,3,NULL);
  xTaskCreate(LKA,"LKA",3000,NULL,3,NULL);
  xTaskCreate(Right_BSW,"Right_BSW",3000,NULL,3,NULL);
  xTaskCreate(Left_BSW,"Left_BSW",3000,NULL,3,NULL);
  xTaskCreate(ALS,"ALS",3000,NULL,1,NULL);
}

void loop(){

}

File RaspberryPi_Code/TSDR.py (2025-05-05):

# =============================
# Include required packages
# =============================
import cv2
from picamera2 import Picamera2
import pandas as pd
from ultralytics import YOLO
import cvzone
import numpy as np
import smbus2
import time

# =============================
# I2C settings
# =============================
I2C_ADDRESS = 0x08  # ESP32 I2C address
bus = smbus2.SMBus(1)  # Use I2C bus 1

# =============================
# Camera settings
# =============================
picam2 = Picamera2()
picam2.preview_configuration.main.size = (640, 480)
picam2.preview_configuration.main.format = "RGB888"
picam2.preview_configuration.align()
picam2.configure("preview")
picam2.start()

# =============================
# Load YOLO model
# =============================
model = YOLO('best.pt')

# =============================
# Load class labels
# =============================
my_file = open("coco1.txt", "r")
data = my_file.read()
class_list = data.split("\n")

# =============================
# I2C signal sending function
# =============================
def send_i2c_signal(signal):
    try:
        bus.write_byte(I2C_ADDRESS, signal)
        print(f"Sent signal: {signal}")
    except Exception as e:
        print(f"Failed to send I2C signal: {e}")

# =============================
# Main Loop
# =============================
count = 0
while True:
    im = picam2.capture_array()

    # Skip Frames for better performance
    count += 1
    if count % 3 != 0:
        continue

    im = cv2.flip(im, -1)
    results = model.predict(im)
    a = results[0].boxes.data
    px = pd.DataFrame(a).astype("float")

    for index, row in px.iterrows():
        x1 = int(row[0])
        y1 = int(row[1])
        x2 = int(row[2])
        y2 = int(row[3])
        d = int(row[5])
        c = class_list[d]

        cv2.rectangle(im, (x1, y1), (x2, y2), (0, 0, 255), 2)
        cvzone.putTextRect(im, f'{c}', (x1, y1), 1, 1)

        # Send signals to ESP32 according to detected object
        if c == 'Speed_60':
            send_i2c_signal(1)
        elif c == 'Speed_120':
            send_i2c_signal(2)
        elif c == 'STOP':
            send_i2c_signal(3)
        else:
            send_i2c_signal(0)

    cv2.imshow("Camera", im)
    if cv2.waitKey(1) == ord('q'):
        break

cv2.destroyAllWindows()
